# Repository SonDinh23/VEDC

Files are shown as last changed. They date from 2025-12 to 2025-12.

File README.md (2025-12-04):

# VEDC.dev

<div align="center">

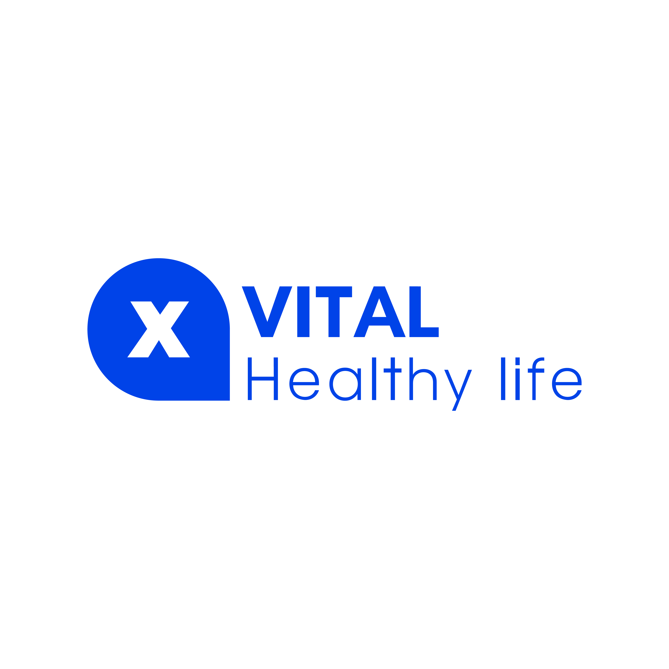
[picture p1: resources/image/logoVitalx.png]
System diagram





<p float="left">
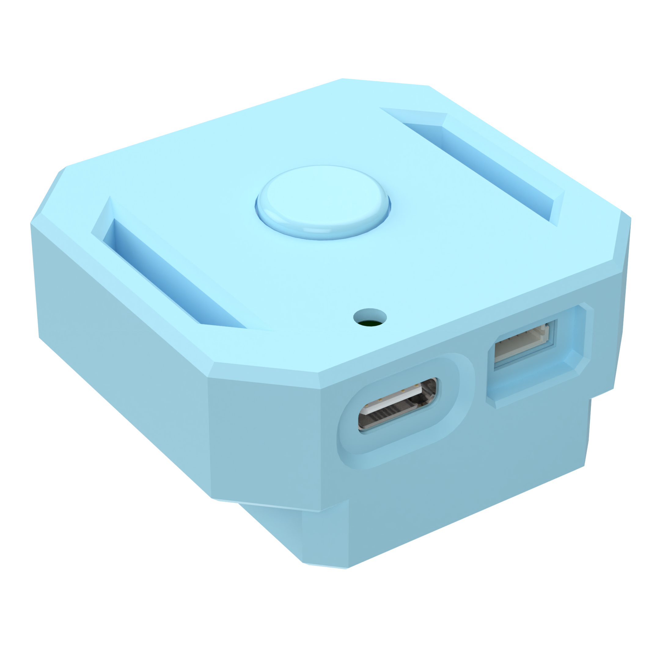
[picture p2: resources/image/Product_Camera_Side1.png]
Product_Camera_Side1

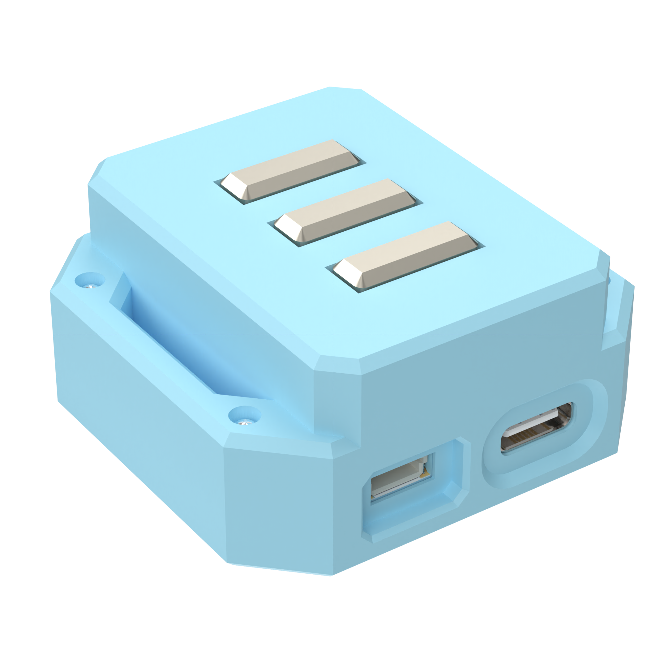
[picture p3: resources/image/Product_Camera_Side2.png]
Product_Camera_Side2

</p>
<sub>
  Vedc v0.1 Front Top product (left), Front Bottom product (right)
</sub>

<p float="left">
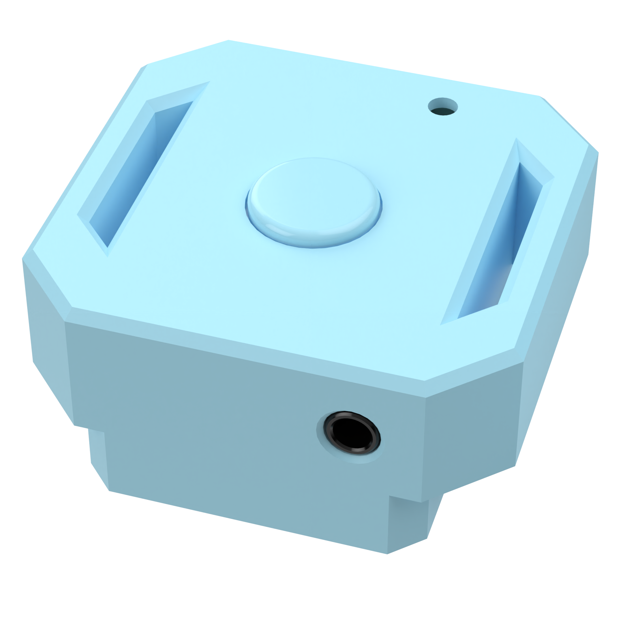
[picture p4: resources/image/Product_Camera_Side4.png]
Product_Camera_Side4

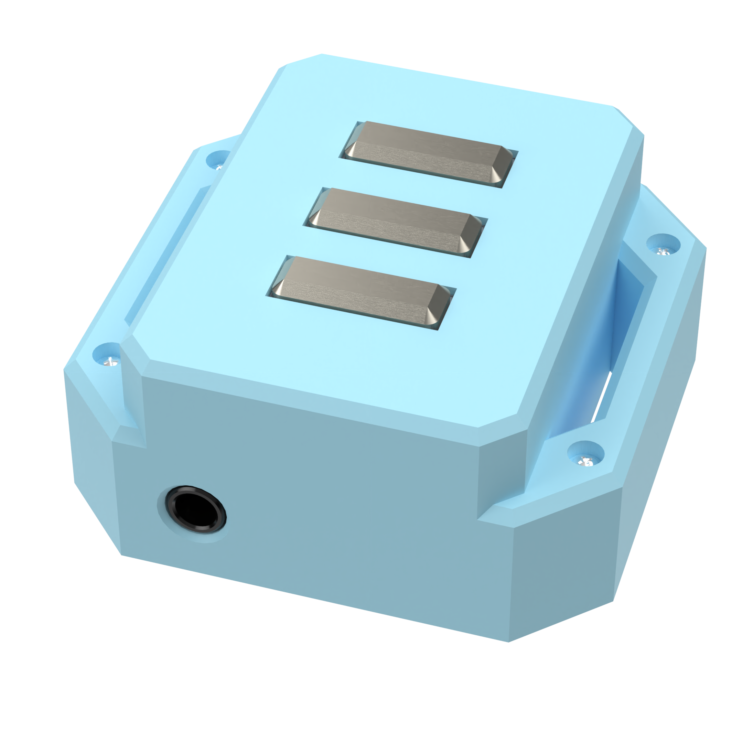
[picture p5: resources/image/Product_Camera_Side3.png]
Product_Camera_Side3

</p>
<sub>
  Vedc v0.1 Back Top product (left), Back Bottom product (right)
</sub>
</div>

## Table of contents

- [About](#about)
- [Platform snapshot](#platform-snapshot)
- [Features](#features)
  - [Hardware](#hardware)
  - [Firmware](#firmware)
  - [Software](#software)
- [Environment & build](#environment--build)
- [Writing apps for the Application Manager](#writing-apps-for-the-application-manager)
- [Licence GPL-3.0](#licence-gpl-30)
- [Thanks](#thanks)

## About

VEDC is a wearable biomedical reference design that blends EMG, ECG, and PPG sensing in a developer-friendly package. The hardware stack is fully captured in KiCad, the firmware targets ESP32-PICO-V3-02 via PlatformIO, and all production assets live in this repo so you can reproduce the build or remix it for your own research.

## Platform snapshot

| Item | Detail |
| --- | --- |
| MCU | ESP32-PICO-V3-02 (dual-core Xtensa®, Wi-Fi + BLE, 8 MB flash, 2 MB PSRAM) |
| Sensors | EMG analog front-end, ECG (AD8232), PPG module, 6-axis IMU, magnetometer |
| Connectivity | Wi-Fi 2.4 GHz, Bluetooth v4.2, USB-C (CP2102N), TWAI®/CAN-ready |
| Power | Single-cell Li-Ion + TP4056 charger + XC6220 LDO + smart power-path on MainPCB |
| Target use | Physiology research, medical wearables prototyping, advanced hobby builds |

### Core silicon & companion parts

- ESP32-PICO-V3-02 ([datasheet](https://documentation.espressif.com/esp32-pico_series_datasheet_en.pdf)) with Xtensa® LX6 up to 240 MHz, Wi-Fi/BLE, Ethernet MAC and TWAI®.
- Torex [XC6220B331MR-G](https://www.farnell.com/datasheets/2012852.pdf) 1 A, 3.3 V low-noise LDO for the digital rail.
- Silicon Labs [CP2102N-A02-GQFN28](https://www.silabs.com/documents/public/data-sheets/cp2102n-datasheet.pdf) USB-to-UART bridge for flashing, logging and live telemetry.
- Worldsemi [WS2812B-2020](https://www.mouser.com/pdfDocs/WS2812B-2020_V10_EN_181106150240761.pdf) RGB indicator, Murata [PKMCS0909E4000-R1](https://pim.murata.com/en-us/pim/details/?partNum=PKMCS0909E4000-R1) piezo buzzer, Microchip [MCP3204](https://ww1.microchip.com/downloads/en/devicedoc/21298e.pdf) SPI ADC.
- ST [LSM6DSL](https://www.st.com/resource/en/datasheet/lsm6dsl.pdf) IMU + [LIS3MDL](https://www.st.com/resource/en/datasheet/lis3mdl.pdf) magnetometer for motion/orientation tracking.
- Analog Devices [AD8232](https://www.analog.com/media/en/technical-documentation/data-sheets/ad8232.pdf) ECG AFE and a custom EMG front-end for bio-signal capture.
- TPASIC [TP4056](https://datasheet.lcsc.com/lcsc/1809261820_TOPPOWER-Nanjing-Extension-Microelectronics-TP4056-42-ESOP8_C16581.pdf) charger IC for USB-powered Li-Ion management.

## Features

### Hardware

- Three KiCad projects: EMGSensor, MainPCB, and PPG_V1.0. Each board section includes schematics, PCB layout, manufacturing outputs, notes, and galleries.
- Design focus on low-noise analog front-ends, modular interconnects, and easy probing during validation.
- Production-ready assets: BOM, pick-and-place, netlist, and positional data are stored under every `production/` folder.

[Browse board documentation →](hardware/README.md)

### Firmware

- ESP-IDF/PlatformIO stack targeting ESP32-PICO-V3-02 with FreeRTOS scheduling, NimBLE-based BLE services, USB-UART telemetry, and low-power modes.
- Sensor pipelines for EMG/ECG/PPG including digital filtering, adaptive baseline tracking, and event triggers for motion artifacts.
- Modular drivers housed under `firmware/Embedded/lib/` plus an application layer that streams metrics to BLE characteristics or logs via UART.
- Includes board bring-up helpers (rail monitors, sensor self-tests) and a configurable command shell.

[Read the full firmware guide →](firmware/README.md)

### Software

- Companion tooling (desktop/mobile) is planned to visualize BLE data streams, annotate sessions, and push OTA payloads.
- Current repo includes assets and API constraints so third parties can prototype dashboards or research tools ahead of the official release.
- Planned features: live waveform view, biomarker extraction scripts, and CSV export for MATLAB/Python workflows.

Have tooling to share? Open an issue so we can link it here.

## Environment & build

### Requirements

- VS Code with the PlatformIO IDE extension (or PlatformIO Core CLI).
- Python 3.10+ (PlatformIO manages the toolchain, but Python is still required).
- KiCad 7+ if you plan to edit the hardware.
- Git LFS for large media assets (images/live captures).

### Quick start

1. Clone the repo: `git clone https://github.com/SonDinh23/VEDC.git && cd VEDC`.
2. Open VS Code -> `firmware/` folder -> PlatformIO will auto-configure the environment.
3. Build: `pio run` (or the PlatformIO Build button).
4. Flash: connect the board over USB-C, then `pio run -t upload`.
5. Monitor logs: `pio device monitor` for UART output, or use the BLE explorer of your choice to view live characteristics.
6. Hardware tweaks: jump into `hardware/README.md` to pick the board you want to fabricate or review.

## Writing apps for the Application Manager

- The Application Manager exposes hooks for real-time sensing apps (recording, feedback) and offline routines (log replay, calibration).
- Apps are plain C++ modules that register tasks, BLE endpoints, and menu entries; use the existing patterns under `firmware/Embedded/src/` and supporting libraries in `firmware/Embedded/lib/` as templates.
- Keep apps lightweight: offload heavy analytics to the companion software via BLE or UART streaming.
- Submit a PR or discussion thread before merging new app types so we can document protocol additions for users.

## Licence GPL-3.0

This project is licensed under the GNU GPLv3.  
Compared to permissive licences like MIT, GPLv3 requires that if you modify this code and distribute your version (including in commercial products), you must also release your changes under the same GPLv3 licence and provide the corresponding source code.  

This way, everyone can benefit from improvements built on top of this project.  
If this licence causes issues for your intended use, feel free to contact me – I’m open to discussing alternatives.

## Thanks

Huge thanks to the open-source communities behind ESP-IDF, PlatformIO, KiCad, and the component vendors whose public documentation made reverse-engineering painless. Additional appreciation goes to early testers who provided waveform captures and enclosure feedback. Reach out if you want to be listed here or contribute design critiques.

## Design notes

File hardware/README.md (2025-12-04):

# 🔧 Hardware Reference

Reference hub for every PCB in the VEDC stack. Each section collects the essential narrative (what the board does), quick specs, manufacturing artifacts, bring-up notes and a gallery that matches the files committed to this repo.

## 📌 At-a-glance

| Board | Functional role | Primary interfaces | Manufacturing kit |
| --- | --- | --- | --- |
| [EMGSensor](#emgsensor) | Surface EMG analog front-end with selectable filtering | Differential electrodes, analog output to MainPCB/ADC | `EMGSensor/*.kicad_*`, `EMGSensor/production/` |
| [MainPCB](#mainpcb) | System backplane: power, MCU, sensor connectors & user IO | USB-C, SPI, I2C, GPIO, battery charger, programming header | `MainPCB/*.kicad_*`, `MainPCB/production/` |
| [PPG_V1.0](#ppg_v10) | Optical heart-rate/SpO2 module (LED driver + TIA) | LED drive, photodiode TIA, analog output to MainPCB | `PPG_V1.0/*.kicad_*`, `PPG_V1.0/production/` |

---

## 🧠 EMGSensor

### Highlights
- Low-noise EMG front-end with band-pass filtering and input protection.
- Differential electrode inputs converted to a conditioned analog output for the main MCU/ADC.
- Designed to keep the analog ground plane quiet and isolated from digital switching noise.

### Quick specs

| Parameter | Detail |
| --- | --- |
| Signal type | Differential surface EMG |
| Input range | Microvolt → millivolt (depends on electrode placement) |
| Bandwidth | Application-configurable band-pass |
| Output | Analog to `MainPCB` or external ADC |

### Manufacturing files
- `EMGSensor/EMGSensor.kicad_sch`
- `EMGSensor/EMGSensor.kicad_pcb`
- `EMGSensor/production/` (BOM, placements, netlist, positions)

### Build & test checklist
- Keep electrode traces short/shielded and preserve the analog ground island.
- Verify input protection and supply rails before connecting electrodes to humans.
- Adjust filter corners so they align with sampling rate and targeted muscle group.

### Gallery

<table>
  <tr>
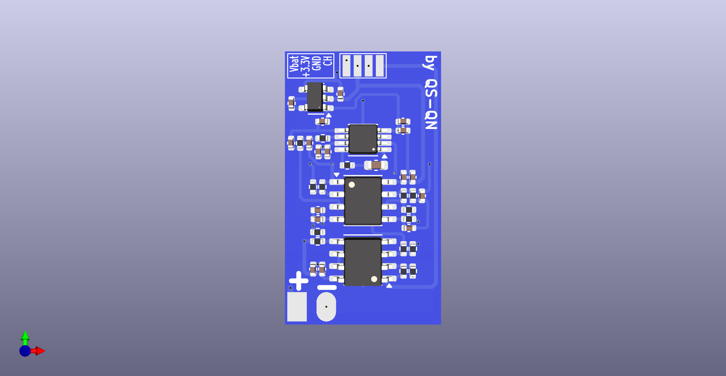
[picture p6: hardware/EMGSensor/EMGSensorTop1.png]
EMGSensor Top 1
    <td align="center"><br><small>Top — module overview</small></td>
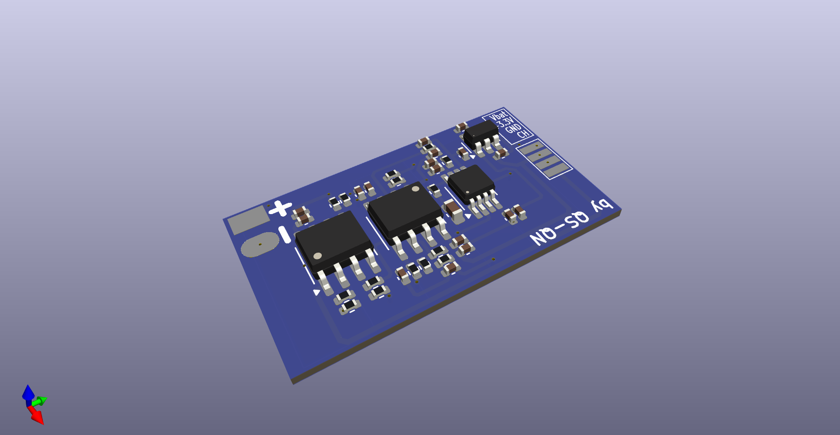
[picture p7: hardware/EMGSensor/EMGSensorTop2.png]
EMGSensor Top 2
    <td align="center"><br><small>Top — amplifier/filter</small></td>
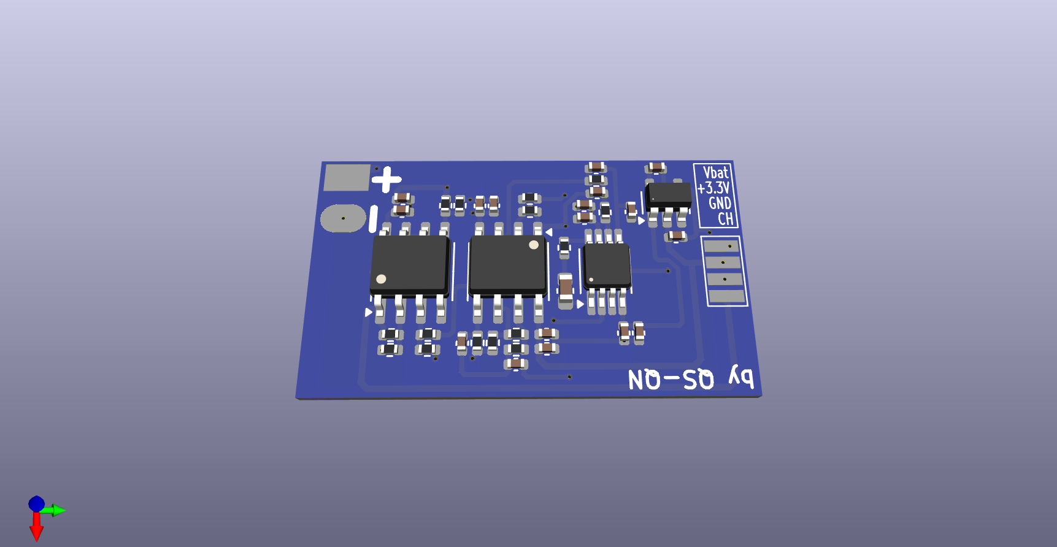
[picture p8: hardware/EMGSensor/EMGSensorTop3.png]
EMGSensor Top 3
    <td align="center"><br><small>Top — connectors</small></td>
  </tr>
  <tr>
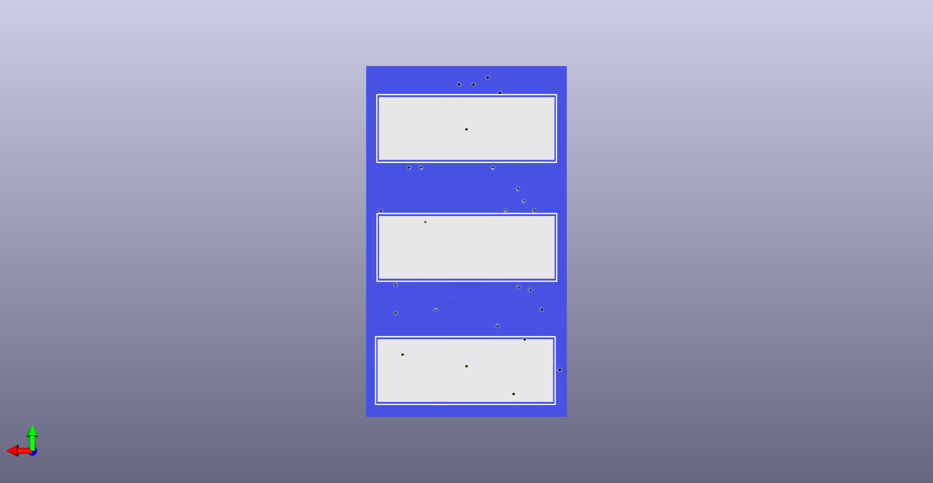
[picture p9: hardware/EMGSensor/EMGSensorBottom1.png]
EMGSensor Bottom 1
    <td align="center"><br><small>Bottom — solder side</small></td>
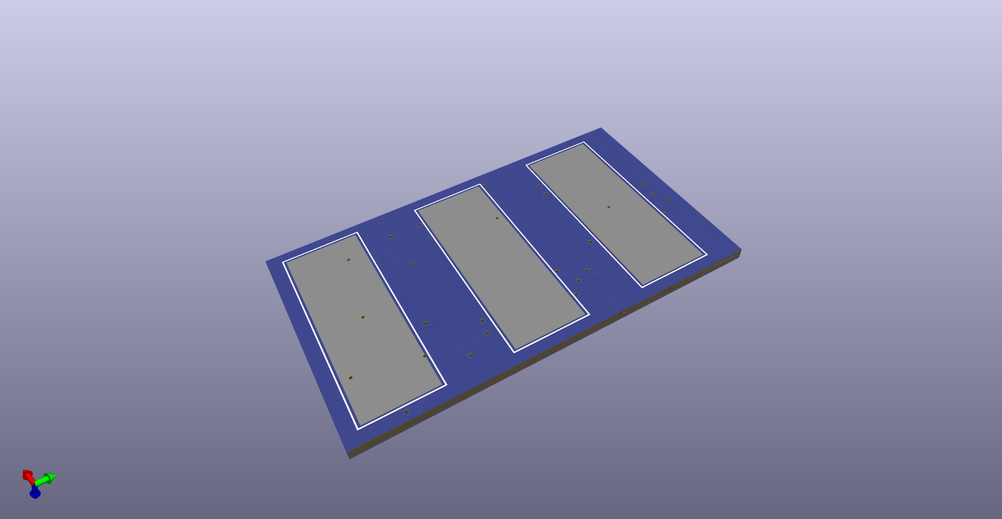
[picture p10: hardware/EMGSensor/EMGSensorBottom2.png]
EMGSensor Bottom 2
    <td align="center"><br><small>Bottom — ground pours</small></td>
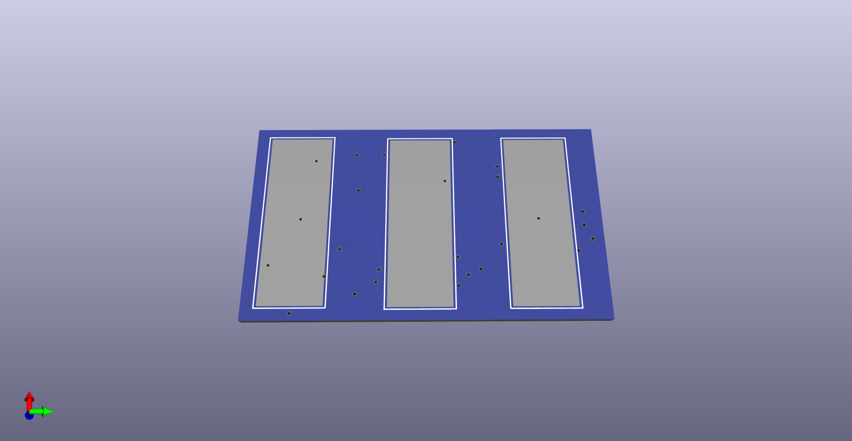
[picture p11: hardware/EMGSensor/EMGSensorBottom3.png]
EMGSensor Bottom 3
    <td align="center"><br><small>Bottom — component placement</small></td>
  </tr>
</table>

---

## 🧭 MainPCB

### Highlights
- Primary compute board with ESP32 module, battery charging/power-path management and sensor interconnects.
- Hosts debug/programming headers, USB-UART bridge, IMU/ADC expansion headers and NeoPixel/buzzer drivers.
- Provides regulated rails (3V3 etc.) and mounting keep-outs for future enclosures.

### Quick specs

| Parameter | Detail |
| --- | --- |
| Core function | Power distribution + embedded processing |
| Key rails | Battery, charger IC, 3V3 LDO, load switches |
| Interfaces | USB/serial, SPI, I2C, ADC, GPIO, programming header |

### Manufacturing files
- `MainPCB/MainPCB.kicad_sch`
- `MainPCB/MainPCB.kicad_pcb`
- `MainPCB/production/` (BOM, placements, netlist, positions)

### Build & test checklist
- Cross-check BOM vs placement before assembly to avoid variant mix-ups.
- Validate mechanical clearances/keep-outs when fitting into an enclosure.
- Probe test points for each rail during bring-up; confirm charger and LDO thermals.

### Gallery

<table>
  <tr>
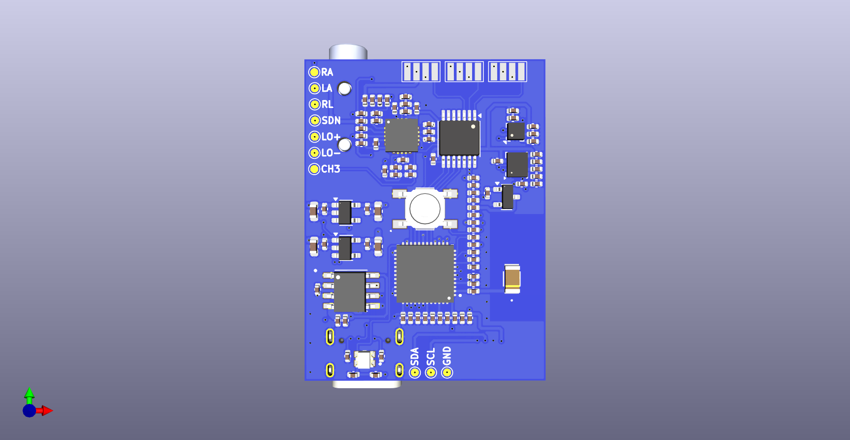
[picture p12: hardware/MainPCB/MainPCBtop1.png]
MainPCB top 1
    <td align="center"><br><small>Top — overview</small></td>
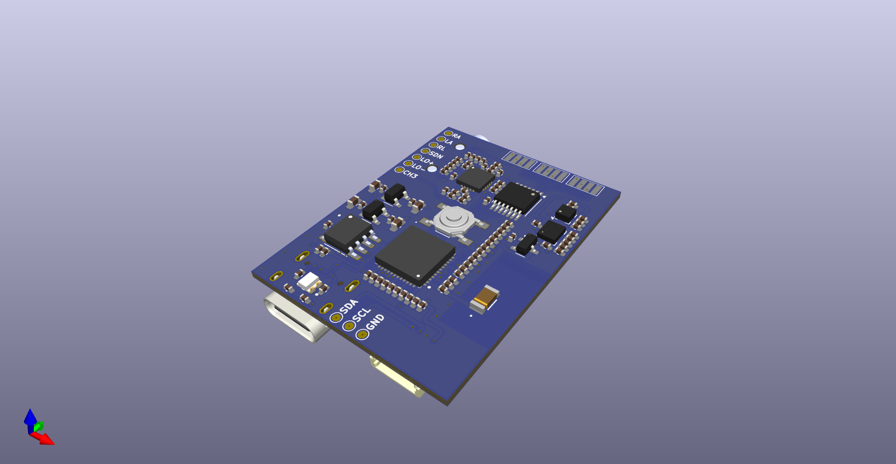
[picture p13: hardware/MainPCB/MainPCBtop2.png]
MainPCB top 2
    <td align="center"><br><small>Top — MCU & IO</small></td>
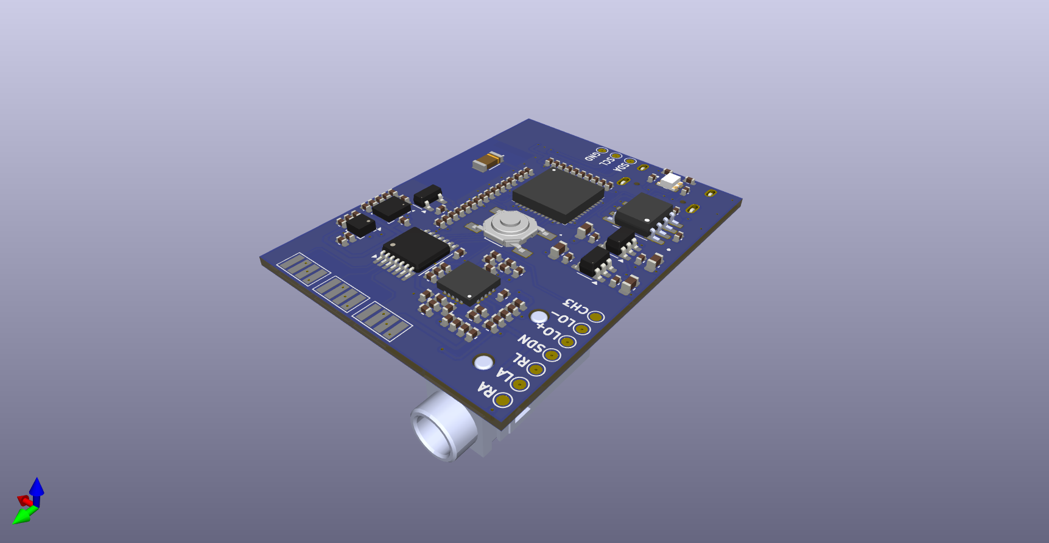
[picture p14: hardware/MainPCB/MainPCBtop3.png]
MainPCB top 3
    <td align="center"><br><small>Top — power subsystem</small></td>
  </tr>
  <tr>
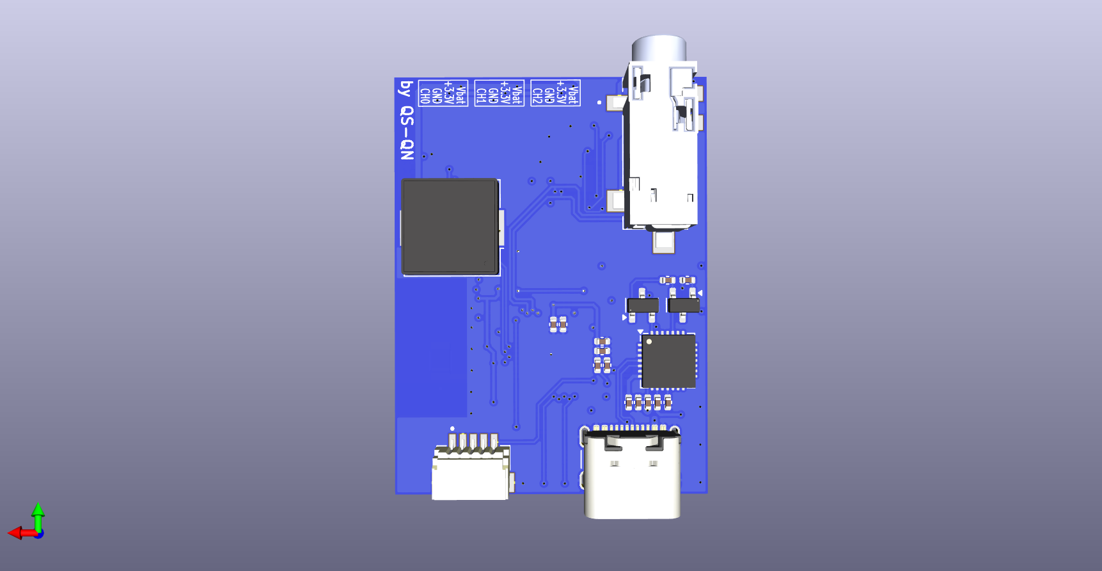
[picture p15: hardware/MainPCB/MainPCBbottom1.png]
MainPCB bottom 1
    <td align="center"><br><small>Bottom — solder side</small></td>
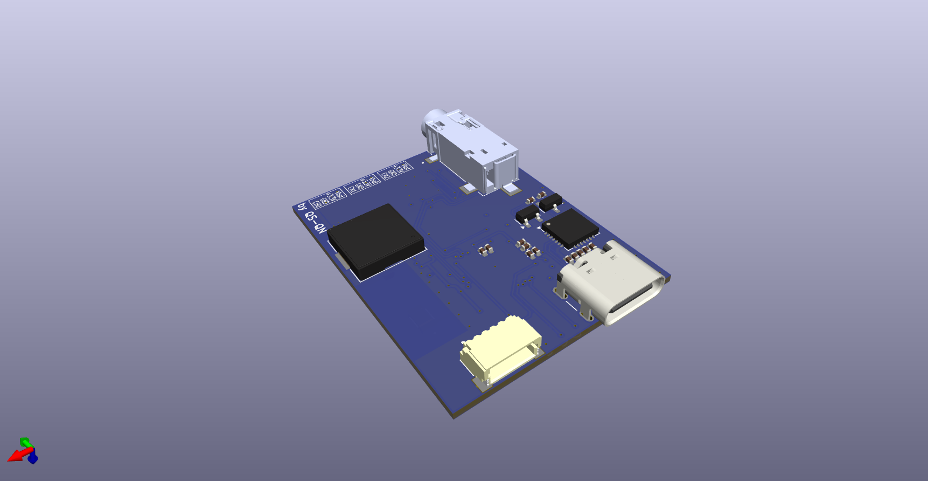
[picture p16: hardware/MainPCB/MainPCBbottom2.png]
MainPCB bottom 2
    <td align="center"><br><small>Bottom — pours & routing</small></td>
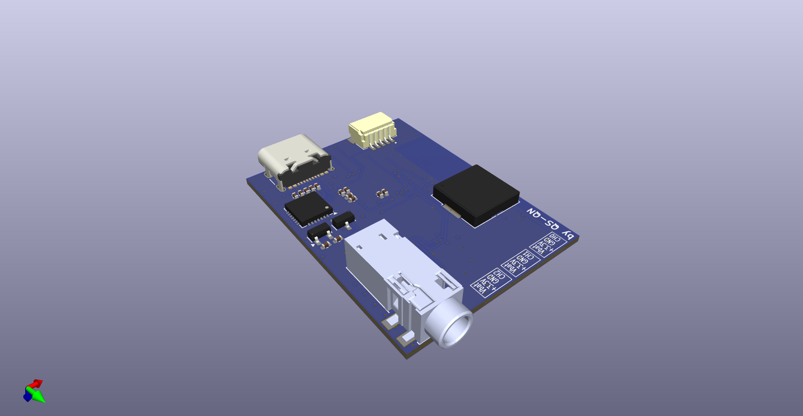
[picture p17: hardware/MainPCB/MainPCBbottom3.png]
MainPCB bottom 3
    <td align="center"><br><small>Bottom — placement</small></td>
  </tr>
</table>

---

## 💡 PPG_V1.0

### Highlights
- Dual-LED photoplethysmography front-end with transimpedance amplifier.
- Layout keeps LED/photodiode path compact to reduce crosstalk and improve tissue coupling.
- Analog output routes directly to MainPCB analog inputs or an external ADC.

### Quick specs

| Parameter | Detail |
| --- | --- |
| Role | Optical heart-rate / blood-volume sensing |
| Key blocks | LED driver, photodetector + TIA, post-filtering |
| Output | Analog to `MainPCB` / ADC |

### Manufacturing files
- `PPG_V1.0/PPG_V1.0.kicad_sch`
- `PPG_V1.0/PPG_V1.0.kicad_pcb`
- `PPG_V1.0/production/` (BOM, placements, netlist, positions)

### Build & test checklist
- Align LEDs and photodiode carefully; even small misalignments affect signal quality.
- Tune LED current and TIA feedback for the target SNR vs power budget.
- Shield the sensor head from ambient light during characterization.

### Gallery

<table>
  <tr>
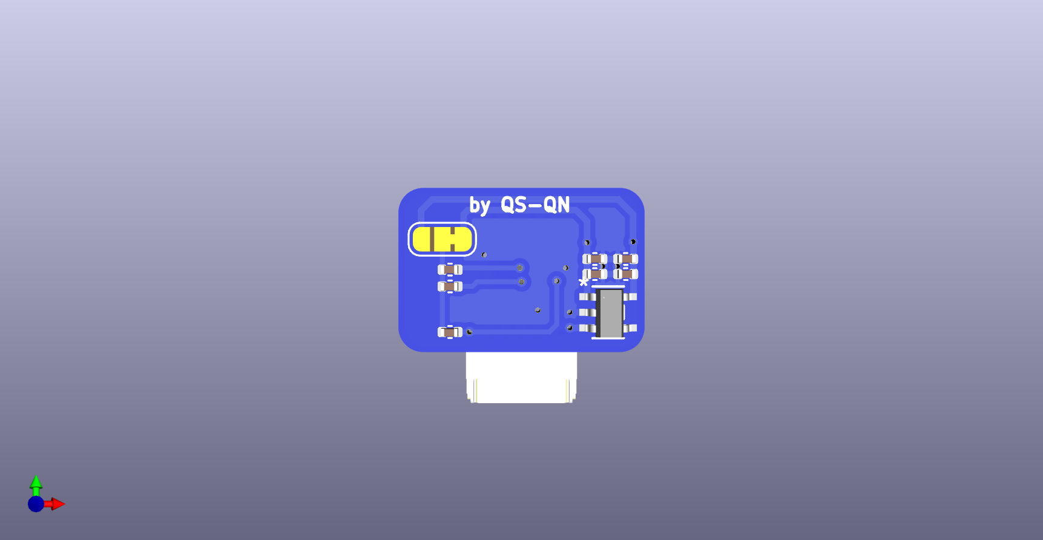
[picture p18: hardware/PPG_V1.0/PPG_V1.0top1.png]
PPG top 1
    <td align="center"><br><small>Top — overview</small></td>
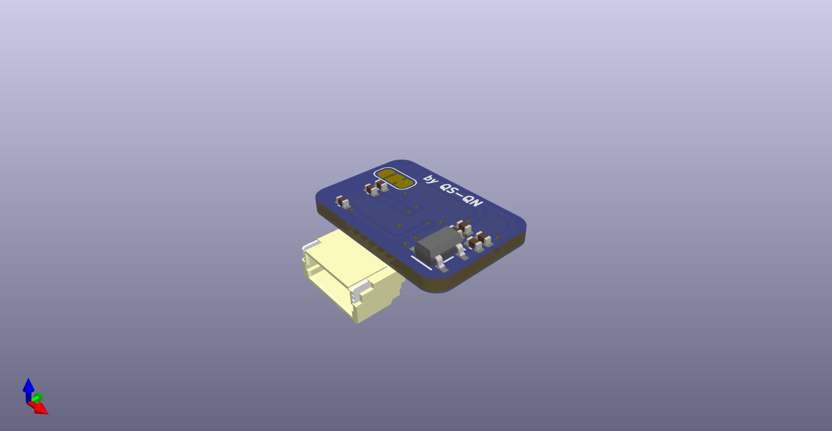
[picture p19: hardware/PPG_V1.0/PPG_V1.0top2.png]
PPG top 2
    <td align="center"><br><small>Top — LED/receiver zone</small></td>
  </tr>
  <tr>
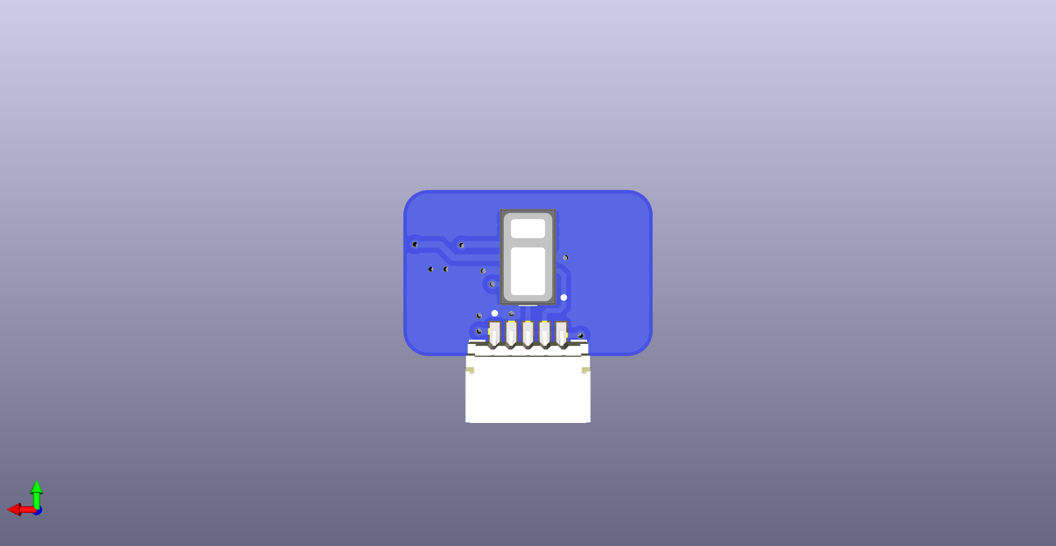
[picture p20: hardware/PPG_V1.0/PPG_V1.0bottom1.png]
PPG bottom 1
    <td align="center"><br><small>Bottom — solder side</small></td>
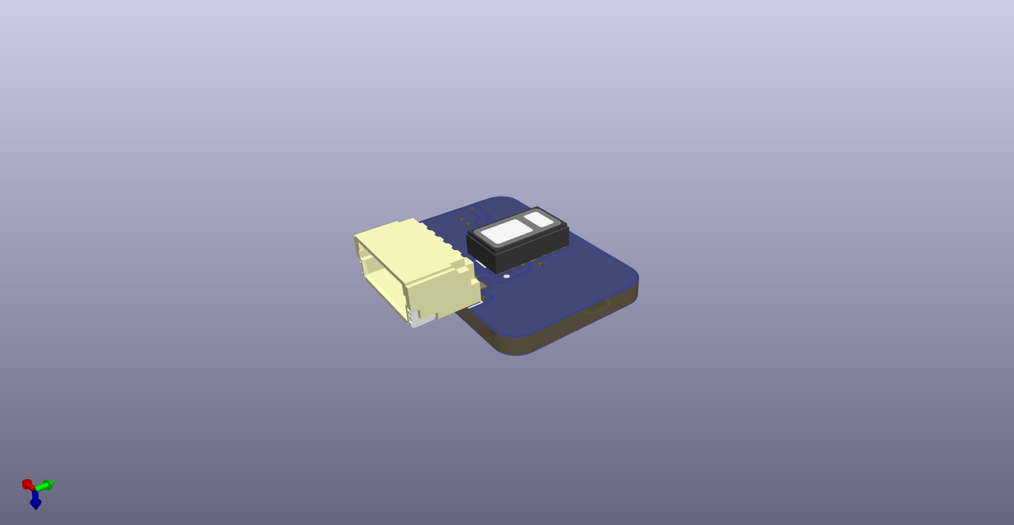
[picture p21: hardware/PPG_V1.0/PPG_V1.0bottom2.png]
PPG bottom 2
    <td align="center"><br><small>Bottom — placement view</small></td>
  </tr>
</table>

---

## 🖼️ Image & path guidance

- Use forward slashes `/` in Markdown image paths; all current links are relative to this README.
- Example snippet: `![EMG front](EMGSensor/EMGSensorTop1.png)`.
- GitHub renders images only after the corresponding PNG/SVG files are committed and pushed.
- Need a different layout (per-board README, thumbnail sizes, PDF gallery)? Let me know and I can spin up that structure quickly.

---

_Last refreshed: see git history for author/date of the latest board update._

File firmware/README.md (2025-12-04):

# ⚙️ Firmware

Firmware for VEDC runs on an ESP32-PICO-V3-02 and is organised as a PlatformIO project under `firmware/Embedded`. The codebase orchestrates EMG/IMU, ECG and PPG sensing, manages power and charging, drives haptic/audio feedback, and exposes a BLE interface (NimBLE) for data streaming, control and OTA firmware updates.

## 📁 Directory layout

| Path | Description |
| --- | --- |
| `Embedded/platformio.ini` | PlatformIO environment (`env:mainVEDC`) configuring ESP32 board, PSRAM/flash, COM ports, build flags and third-party libraries. |
| `Embedded/src/MainVEDC.cpp` | Main application entry: hardware bring-up, FreeRTOS task creation, BLE orchestration, power management loop. |
| `Embedded/lib/Son_WearableSensor` | Sensor pipeline (EMG, ECG, PPG, IMU fusion), data encoding and buffer publication. |
| `Embedded/lib/Son_BLEPeripheral` | BLE stack (Information + Controller services), OTA handler, advertising helpers. |
| `Embedded/lib/Son_BLEServiceManager` | Helper template for registering NimBLE characteristics/read-write/notify callbacks. |
| `Embedded/lib/Son_BuzzerMusic` | LEDC-based buzzer driver with predefined alert tones. |
| `Embedded/lib/Son_LSM6DSL` | Driver and helpers for the ST LSM6DSL IMU (I²C/SPI). |
| `Embedded/lib/Son_Filter` | Utility macros (low-pass filters, half-float conversion, mapping helpers). |
| `Embedded/include/` | Place for project-wide headers (PlatformIO convention). |
| `.pio/`, `.vscode/`, `test/` | Build artifacts, VS Code configuration, and PlatformIO test scaffolding. |

## 🧩 System architecture

- **Hardware targets**: ESP32-PICO-V3-02 (`esp32dev` profile) with 8 MB flash, PSRAM enabled (`-DBOARD_HAS_PSRAM`, `-mfix-esp32-psram-cache-issue`). External peripherals include MCP3204 ADC (EMG/ECG), MAX30105 PPG sensor, LSM6DSL IMU, LIS3MDL magnetometer, LED driver, buzzer, and WS2812 NeoPixel indicator.
- **RTOS tasks** (created from `setup()`): dedicated FreeRTOS tasks for EMG/IMU, ECG, PPG, “all sensors”, BLE sync, and a Manager task. Tasks are coordinated via `isRunningTaskSystem[]` flags and suspended/resumed depending on the active sensing mode.
- **Modes**: `MODE_WEARABLE_EMG_IMU`, `MODE_WEARABLE_ECG`, `MODE_WEARABLE_PPG`, `MODE_WEARABLE_ALL`, selected through BLE Controller characteristic. Modes are persisted via `Preferences` so devices restart in last-used mode.
- **Feedback + power**: NeoPixel colour indicates current mode or status, buzzer plays cues (connect, warning, OTA, low battery). Power management monitors charger pins, battery sense, handles deep sleep, wake-up by button/GPIO, and triggers low-battery alarms.
- **Communication**: NimBLE-based GATT server exposes two services: Information (version/name/hardware + OTA) and Controller (mode selection + sensor/battery notifications). BLE MTU set to 517 bytes for efficient streaming.

## 🔄 Runtime flow

1. **Boot & init**: `setup()` configures GPIO, SPI, ADC, NeoPixel, buzzer and sensors, then starts BLE and waits for optional button-triggered wake. PSRAM and SPIFFS are initialised to cache calibration data.
2. **BLE connection window**: `BLEPeripheral::waitConnect()` advertises for up to 60 s while pulsing LEDs/buzzer. If no connection occurs, the device can enter sleep depending on button state.
3. **Sensor tasks**: Once running, tasks continuously sample their respective sensors. Manager task monitors BLE mode selection and resumes/suspends tasks, updates LED colour, and keeps a running battery estimate.
4. **Data path**: Sensor classes push processed samples into `bufferNotify*` arrays. `BLEPeripheral::notifyData()` calls the appropriate Controller notify function, which sends packets as half-floats/uint32 via GATT characteristics.
5. **Power supervision**: `onPower()` polls button, BLE state and charger lines. It enforces timeouts, restarts advertising if disconnected, alarms on low battery (<15 %) and forces sleep below 5 %.
6. **Sleep/OTA**: Button long-press toggles deep sleep via `onSleep()`/`deepSleep()`. OTA is handled entirely over BLE (see below).

## 🧪 Sensor pipelines & algorithms

### ⚡ EMG + IMU
- Sampling: MCP3204 channel read at ~1 kHz (`CYCLE = 1000 µs`).
- Filtering: High-pass (KickFiltersRT) followed by configurable Kalman filter; EMG stored as half-float. IMU orientation uses a quaternion-based fusion (Madgwick-style) combining LSM6DSL gyro/accel with LIS3MDL magnetometer (tilt-compensated heading + complementary filter on yaw).
- Output payload: EMG magnitude + roll, pitch, yaw + elapsed cycle time.

### ❤️ ECG
- Hardware: MCP3204 differential inputs with lead-off detection pins (`PIN_LO_POSITIVE_ECG`, `PIN_LO_NEGATIVE_ECG`).
- Processing chain: high-pass filter (1st order), derivative, squaring, moving window integral (Pan–Tompkins inspired). Adaptive thresholds track signal/noise peaks; RR intervals filtered via EMA to compute heart rate.
- Output payload: lead status bits, filtered analog sample, heart rate half-float.

### 💡 PPG (MAX30105)
- Acquisition: Red/IR LEDs, 100 sps sample rate, decimated by factor 4 for bandwidth reduction. Buffer length 100 samples (~4 s) with recomputation stride 25 samples.
- Algorithms: Maxim `maxim_heart_rate_and_oxygen_saturation()` for HR / SpO₂; EMA smoothing for HR; logistic regression (`logistic_model`) fuses HR + SpO₂ to estimate SmO₂.
- Output payload: raw Red/IR (32-bit), filtered HR/SpO₂/SmO₂ half-floats.

### 🔋 Battery & charging
- `getBattery()` converts ADC millivolts (voltage divider) into percentage with clamping between `BATTERY_MIN` (3.2 V) and `BATTERY_MAX` (4.15 V). Thresholds trigger blink/beep alarms and enforced sleeps; charging detection resets CPU if charger inserted while running (in non-debug builds).

## 📡 BLE stack & OTA

- **Information service** (`WEARABLE_INFORMATION_SERVICE_UUID`)
	- Characteristics: OTA (`OTA_CHAR_UUID`), Device Name, Hardware Name.
	- OTA process: client writes `START_OTA`, streams binary chunks, writes `END_OTA`. ESP32 writes to next OTA partition via `esp_ota_begin/esp_ota_write/esp_ota_end` and reboots when complete.
	- Device name/hardware stored in NVS (`Preferences`) and mirrored to advertisement data.

- **Controller service** (`WEARABLE_CONTROLLER_SERVICE_UUID`)
	- Characteristics: Mode select, EMG/IMU notify, ECG notify, PPG notify, All-sensor (reserved), Battery notify.
	- Notifications use MTU 517 for efficient 20+ byte packets. Mode writes accept ASCII digits representing `mode_wearable_sensor_t` enum.

## 🛠️ Building & flashing

Requirements: PlatformIO CLI or VS Code extension, ESP32 toolchain, USB connection recognised as `COM3` (adjust as needed).

	# 1. Install deps (once)
	pip install platformio

	# 2. Build
	cd firmware/Embedded
	pio run -e mainVEDC

	# 3. Flash firmware (ensure board on COM3)
	pio run -e mainVEDC -t upload

	# 4. Open serial monitor at 115200 baud
	pio device monitor -p COM3 -b 115200

Key build settings (`platformio.ini`):
- `platform = espressif32 @ 6.11.0`, `framework = arduino`, `board = esp32dev`.
- PSRAM/flash config via `board_build.*` options (8 MB QIO, custom partitions `default_8MB.csv`).
- External libraries: MCP320x, SparkFun MAX3010x, SimpleKalmanFilter, KickMath/KickFiltersRT, ESP32Time, NimBLE-Arduino, ArduinoJson, Adafruit NeoPixel + LIS3MDL.

## ⚠️ Operational notes & cautions

- **Task watchdog**: `esp_task_wdt` is fed in sensor loops and OTA handler—avoid adding blocking code without feeding WDT.
- **PSRAM**: Build flags enable PSRAM cache workaround; ensure board definition matches hardware (otherwise random crashes may occur).
- **Sensor grounding**: EMG/ECG inputs are high-impedance and sensitive—maintain shielding and protect against ESD when connecting electrodes.
- **Battery thresholds**: `BATTERY_MIN/BATTERY_MAX` are calibrated for single-cell Li-ion. Adjust if using different chemistry.
- **BLE OTA**: Client must honour START/END messages and send chunks quickly; abort resets OTA session. Ensure adequate battery before OTA.
- **Button handling**: Long press toggles sleep; double-check `PIN_BUTTON` wiring before changing logic to avoid stuck-sleep states.

## 🚀 Extending the firmware

- Add new sensors by extending `WearableSensor` (new mode, buffer, encoder) and exposing a characteristic via `BLEController`.
- To adjust sampling or filtering, modify constants (`FS`, `CYCLE`, Kalman gains, logistic coefficients) inside `Son_WearableSensor` and reflash.
- For additional UI cues, update `BuzzerMusic` or NeoPixel colours inside `ManagerOP` when entering modes.

For questions or contributions, open an issue or pull request in this repository. When contributing code, run `pio run -e mainVEDC` before submitting to ensure the firmware compiles.

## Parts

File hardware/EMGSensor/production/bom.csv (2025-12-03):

Designator | Footprint | Quantity | Value | LCSC Part #
_2, |  | 2
C1, C14, C24, C3, C9 | 0402 | 5 | 4.7uF
C10, C13, C15, C2, C23, C25, C26, C27, C28 | 0402 | 9 | 100nF
C11 | 0603 | 1 | 10uF
C12, C22, C5 | 0402 | 3 | 1uF
R1 | 0402 | 1 | 220R
R14 | 0402 | 1 | 2.8K
R15, R19, R21, R6 | 0402 | 4 | 1K
R16, R20, R5 | 0402 | 3 | 3.6K
R17 | 0402 | 1 | 22K
R18 | 0402 | 1 | 33K
R2, R3 | 0402 | 2 | 100K
R4, R7 | 0402 | 2 | 2K
U1 | VSSOP-8_3x3mm_P0.65mm | 1 | INA333xxDGK
U10 | Pad 1 | 1 | Pad
U11 | SOT-23-5 | 1 | TPS60402DBV
U12, U2 | SOIC-8_3.9x4.9mm_P1.27mm | 2 | MCP602
U13 | Pad 4 | 1 | Pad 4
U7 | Pad Battery | 1 | Pad_Battery

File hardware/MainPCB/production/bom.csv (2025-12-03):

Designator | Footprint | Quantity | Value | LCSC Part #
AE1 | ANT_16060A1T_WAL | 1 | RFECA3216060A1T
BZ1 | Buzzer_Murata_PKMCS0909E | 1 | Buzzer
C1, C22, C24, C26, C28 | 0402 | 5 | 1uF
C10, C12, C14, C16, C19, C2, C29, C31, C36, C38, C4, C40, C42, C6, C8 | 0402 | 15 | 4.7uF
C11, C13, C15, C17, C18, C3, C30, C32, C33, C34, C37, C39, C41, C43, C5, C7, C9 | 0402 | 17 | 100nF
C20, C46 | 0402 | 2 | 10nF
C21, C23, C25, C27 | 0603 | 4 | 22uF
C44 | 0402 | 1 | 1nF
C45, C48 | 0402 | 2 | 0.33uF
C47 | 0402 | 1 | 1.5nF
C49, C50 | 0402 | 2 | 0.1uF
D2 | LED_WS2812B2020 | 1 | WS2812B2020
J1 | USB_C_Receptacle_GCT_USB4105-xx-A_16P_TopMnt_Horizontal | 1 | USB_C_Receptacle_USB2.0_16P
J2 | CUI_SJ2-3593D-SMT-TR | 1 | SJ2-3593D-SMT-TR
J3 | JST_SM05B-SRSS-TB_LF__SN_ | 1 | SM05B-SRSS-TB_LF__SN_
Q1, Q2 | SOT-23 | 2 | SS8050
Q3 | SOT-23 | 1 | MMBT2222A
R1, R16, R3, R6 | 0402 | 4 | 0R
R10, R11, R12, R13, R14, R15, R2, R22, R23, R24, R45 | 0402 | 11 | 10K
R17 | 0402 | 1 | 3K
R18, R19, R20 | 0402 | 3 | 200K
R21 | 0402 | 1 | 300K
R25, R43 | 0402 | 2 | 0
R26, R44 | 0402 | 2 | DNP
R27, R30, R34, R35, R37 | 0402 | 5 | 1M
R28, R29 | 0402 | 2 | 1K
R31, R32 | 0402 | 2 | 180K
R33 | 0402 | 1 | 360K
R36 | 0402 | 1 | 100K
R38, R39, R41, R42 | 0402 | 4 | 10M
R4, R5 | 0402 | 2 | 5.1K
R40 | 0402 | 1 | 1.4M
R7 | 0402 | 1 | 4.7K
R8 | 0402 | 1 | 24K
R9 | 0402 | 1 | 47K
S1 | SW_TL3342F160QG | 1 | TL3342F160QG
TP1, TP10, TP2, TP3, TP4, TP5, TP6, TP7, TP8, TP9 | TestPoint_Pad_D1.0mm | 10 | TestPoint_Small
U1 | XCVR_ESP32-PICO-V3-02 | 1 | ESP32-PICO-V3-02
U10, U8, U9 | Pad 4 | 3 | Pad 4
U13 | LFCSP_20 | 1 | AD8232
U15, U5 | SOT-23-5 | 2 | XC6220B331MR
U2 | QFN-28-1EP_5x5mm_P0.5mm_EP3.35x3.35mm | 1 | CP2102N-Axx-xQFN28
U3 | LGA-14_3x2.5mm_P0.5mm_LayoutBorder3x4y | 1 | LSM6DSL
U4 | TSSOP-14_4.4x5mm_P0.65mm | 1 | MCP3204
U6 | SOP127P600X175-9N | 1 | TP4056
U7 | LGA-12_2x2mm_P0.5mm | 1 | LIS3MDL

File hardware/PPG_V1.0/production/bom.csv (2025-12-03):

Designator | Footprint | Quantity | Value | LCSC Part #
C20, C3 | 0402 | 2 | 100nF
C4, C5 | 0402 | 2 | 4.7uF
J3 | JST_SM05B-SRSS-TB_LF__SN_ | 1 | SM05B-SRSS-TB_LF__SN_
R1, R2, R3 | 0402 | 3 | 472
U1 | XDCR_MAX30101EFD_ | 1 | MAX30102EFD_T
U3 | SOT-25_TOR | 1 | XC6220B181MR-G

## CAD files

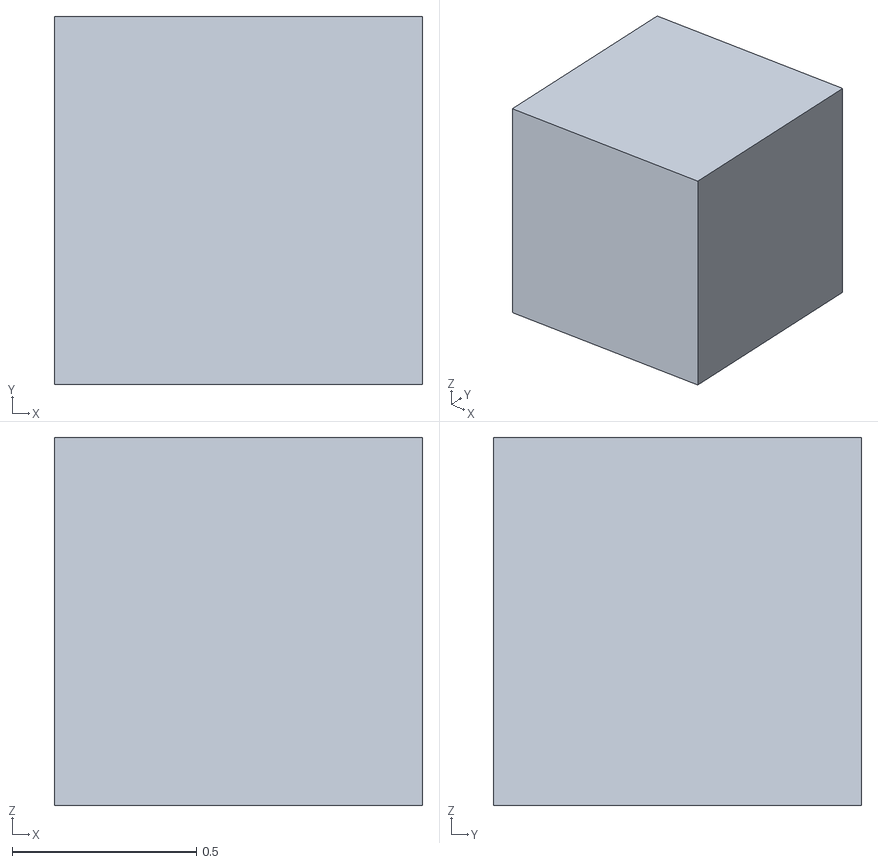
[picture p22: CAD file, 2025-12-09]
app/app_vedc/assets/models/imu.obj
1.00 x 1.00 x 1.00

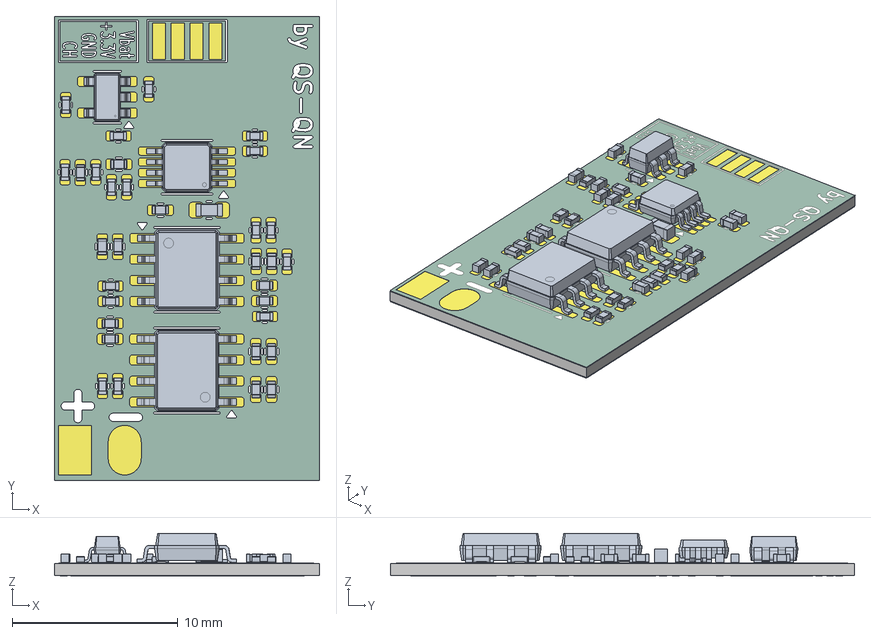
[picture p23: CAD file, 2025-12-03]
hardware/EMGSensor/EMGSensor.step
16.0 x 28.0 x 2.62 mm
C_0402_1005Metric x 17
R_0402_1005Metric x 15
SOT-23-5
SOIC-8_3.9x4.9mm_P1.27mm x 2
VSSOP-8_3x3mm_P0.65mm
C_0603_1608Metric
EMGSensor_copper
EMGSensor_silkscreen
EMGSensor_soldermask
EMGSensor_PCB

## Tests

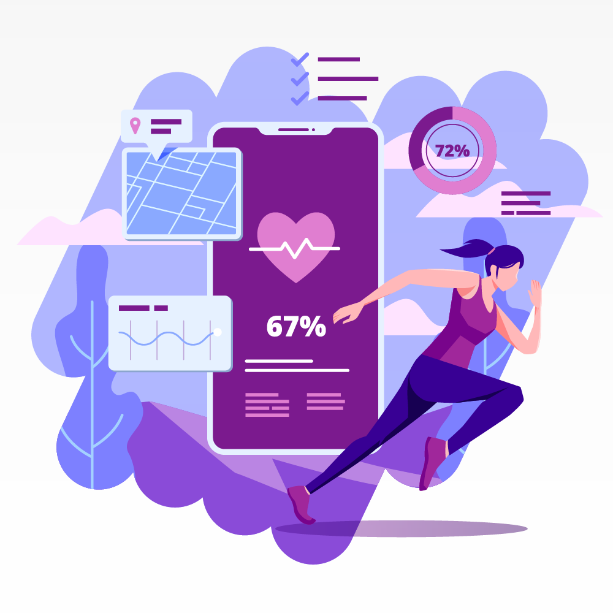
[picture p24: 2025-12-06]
app/app_vedc/assets/images/on_boarding_images/measurement_and_testing.png

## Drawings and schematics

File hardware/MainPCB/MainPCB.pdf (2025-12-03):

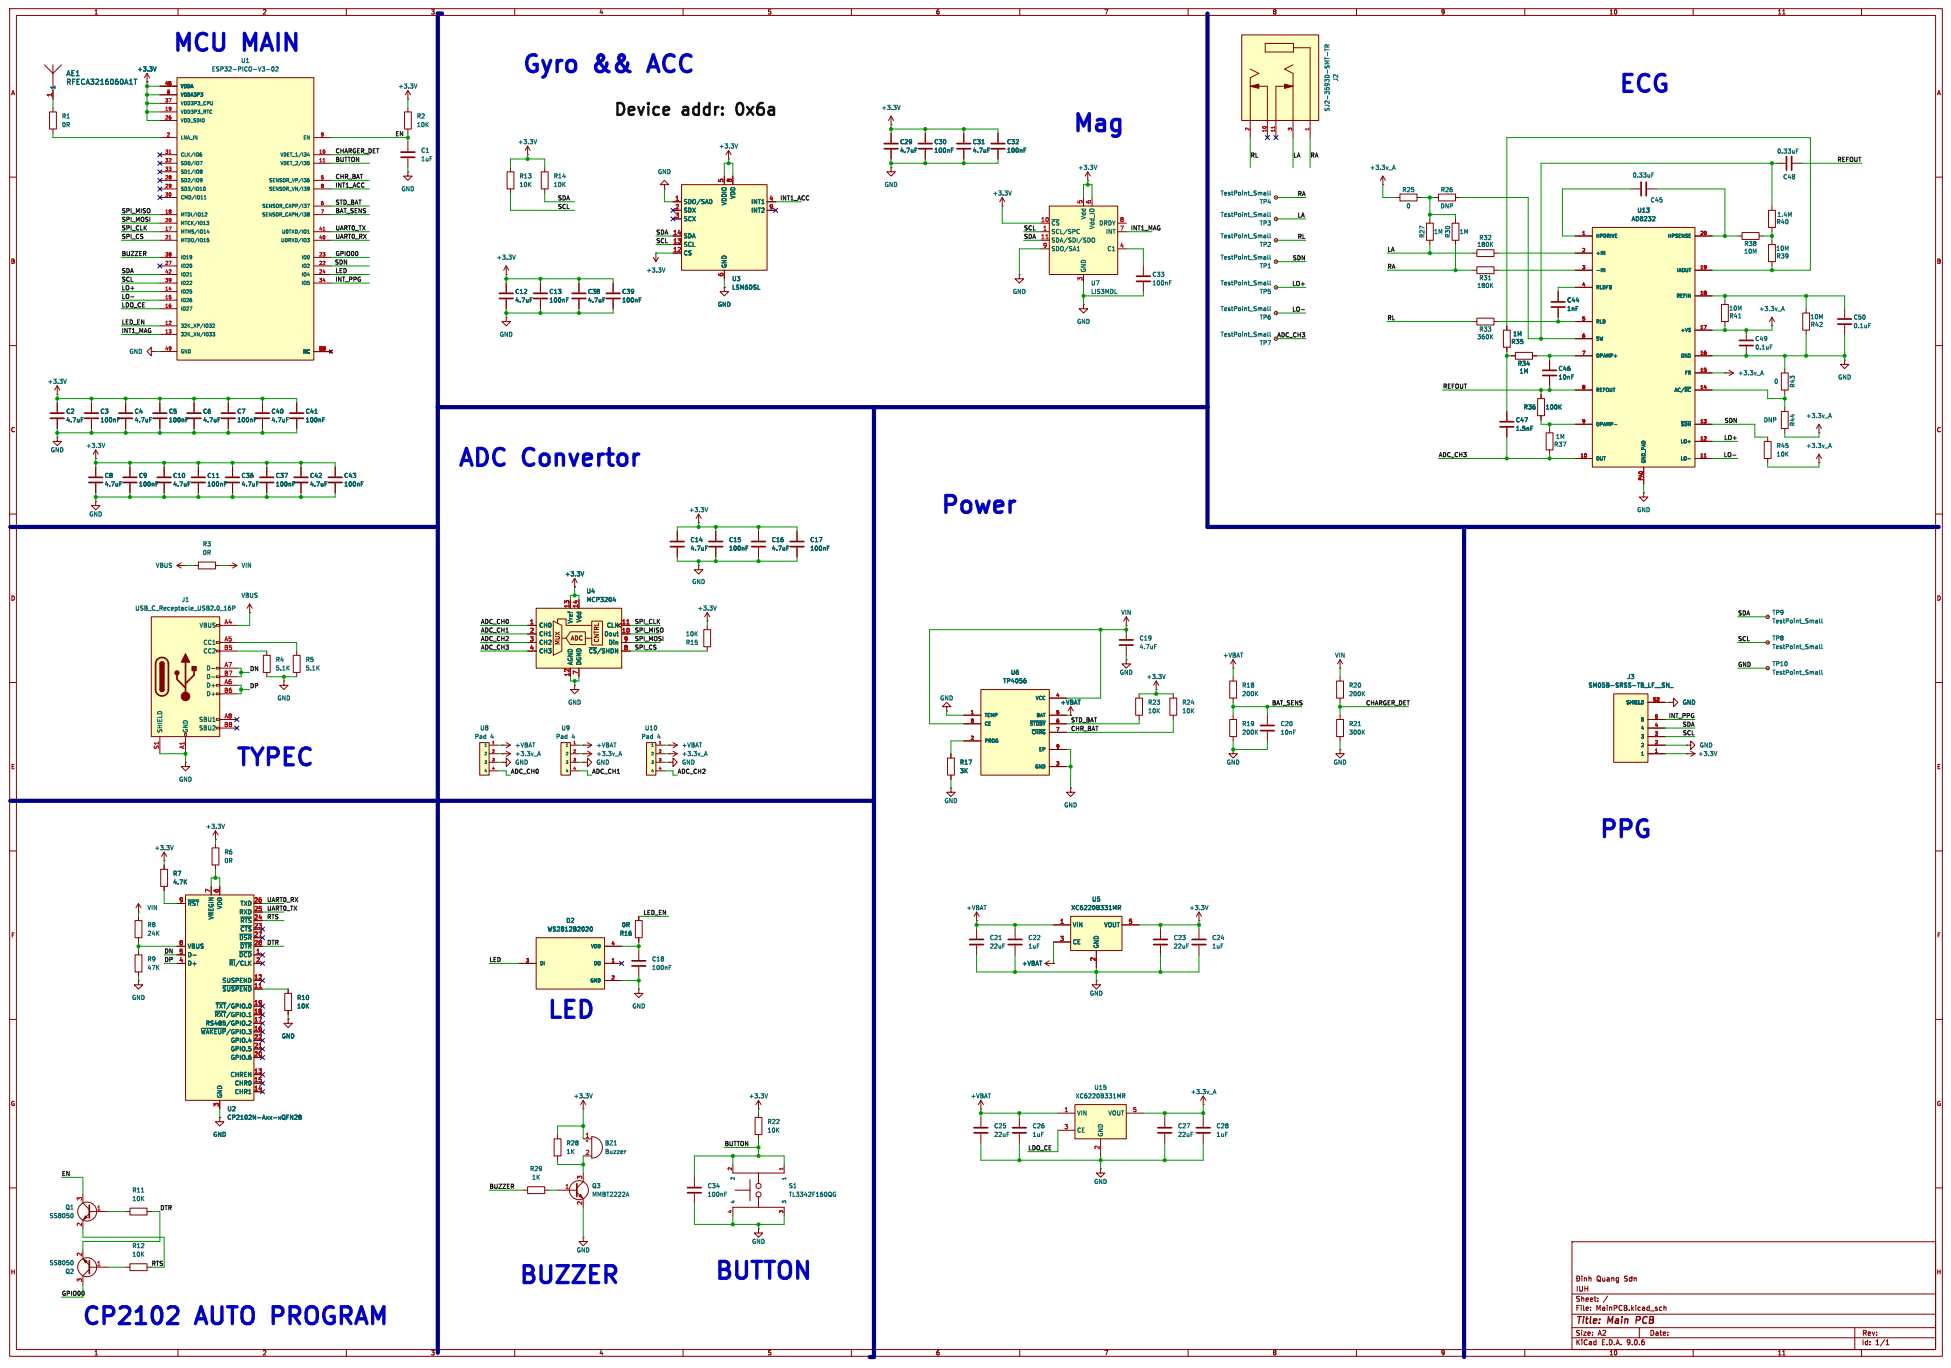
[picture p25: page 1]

7 CLK 11 Dout 10 Din 9 ~{CS}/SHDN 8 U4 MCP3204

7 CLK 11 Dout 10 Din 9 ~{CS}/SHDN 8 R7

3 TXD 26 RXD 25 ~{RTS} 24 ~{CTS} 23 ~{DSR} 27 ~{DTR} 28 ~{DCD}1 ~{RI}/CLK2 SUSPEND 12 ~{SUSPEND}11 ~{TXT}/GPIO.019 ~{RXT}/GPIO.118 RS485/GPIO.2 17 ~{WAKEUP}/GPIO.316 GPIO.4 22 GPIO.5 21 GPIO.6 20 CHREN 13 CHR0 15 CHR1 14 U2 CP2102N-Axx-xQFN28 GND GND
VIN

3 TXD 26 RXD 25 ~{RTS} 24 ~{CTS} 23 ~{DSR} 27 ~{DTR} 28 ~{DCD}1 ~{RI}/CLK2 SUSPEND 12 ~{SUSPEND}11 ~{TXT}/GPIO.019 ~{RXT}/GPIO.118 RS485/GPIO.2 17 ~{WAKEUP}/GPIO.316 GPIO.4 22 GPIO.5 21 GPIO.6 20 CHREN 13 CHR0 15 CHR1 14 GND

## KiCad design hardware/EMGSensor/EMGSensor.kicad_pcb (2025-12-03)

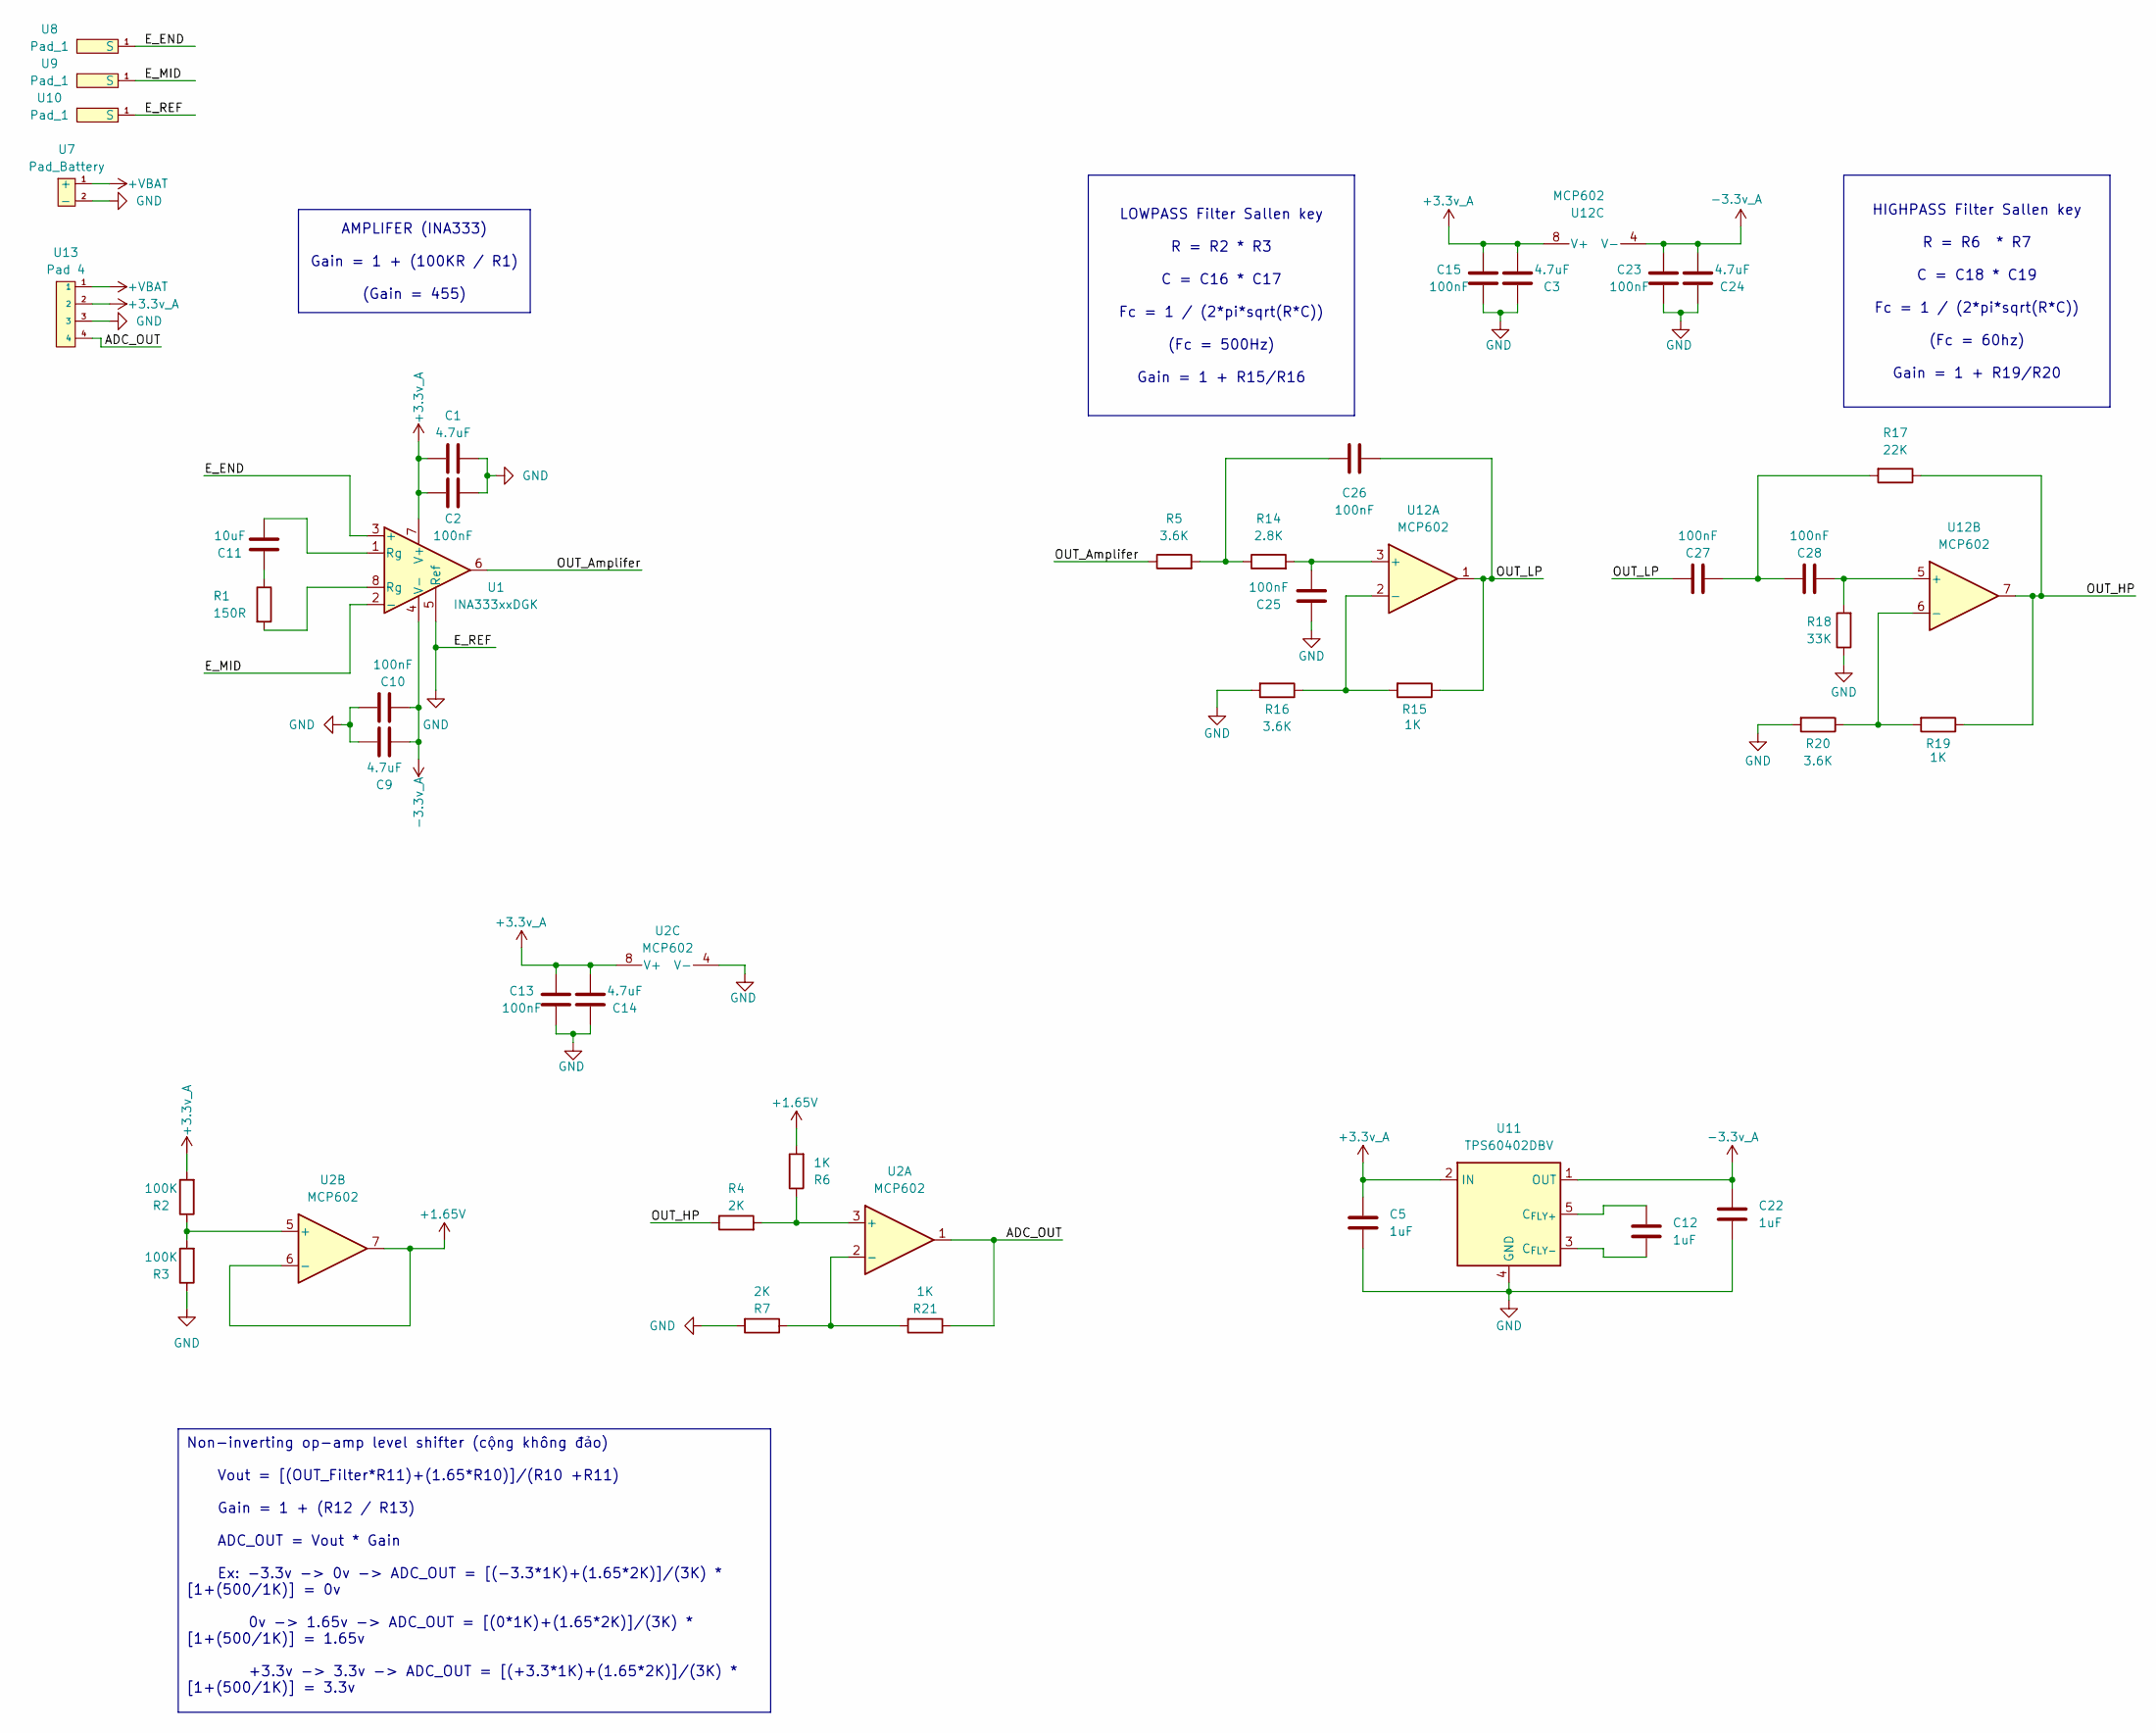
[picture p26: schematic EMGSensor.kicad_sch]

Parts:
C1, C3, C9, C14, C24: 4.7uF; C_0402_1005Metric
C2, C10, C13, C15, C23, C25, C26, C27, C28: 100nF; C_0402_1005Metric
C5, C12, C22: 1uF; C_0402_1005Metric
C11: 10uF; C_0603_1608Metric
R1: 150R; R_0402_1005Metric
R2, R3: 100K; R_0402_1005Metric
R4, R7: 2K; R_0402_1005Metric
R5, R16, R20: 3.6K; R_0402_1005Metric
R6, R15, R19, R21: 1K; R_0402_1005Metric
R14: 2.8K; R_0402_1005Metric
R17: 22K; R_0402_1005Metric
R18: 33K; R_0402_1005Metric
U1: INA333xxDGK; VSSOP-8_3x3mm_P0.65mm
U2, U12: MCP602; SOIC-8_3.9x4.9mm_P1.27mm
U7: Pad_Battery; Pad Battery
U8, U9, U10: Pad_1; Pad 1
U11: TPS60402DBV; SOT-23-5
U13: Pad 4

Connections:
+1.65V: R6.2, U2.6 (-), U2.7
+3.3v_A: C1.1, C2.1, C3.1, C5.1, C13.1, C14.1, C15.1, R2.2, U1.7 (V+), U2.8 (V+), U11.2 (IN), U12.8 (V+), U13.2
+VBAT: U7.1 (+), U13.1
-3.3v_A: C9.1, C10.1, C22.1, C23.1, C24.1, U1.4 (V-), U11.1 (OUT), U12.4 (V-)
/ADC_OUT: R21.1, U2.1, U13.4
/E_END: U1.3 (+), U8.1
/E_MID: U1.2 (-), U9.1
/OUT_Amplifer: R5.1, U1.6
/OUT_HP: R4.1, R17.1, R19.1, U12.7
/OUT_LP: C26.1, C27.2, R15.1, U12.1
GND: C1.2, C2.2, C3.2, C5.2, C9.2, C10.2, C13.2, C14.2, C15.2, C22.2, C23.2, C24.2, C25.1, R3.1, R7.2, R16.2, R18.1, R20.2, U1.5 (Ref), U2.4 (V-), U7.2 (-), U10.1 (S), U11.4 (GND), U13.3
unnamed: C11.1, R1.1
unnamed: C11.2, U1.1 (Rg)
unnamed: C26.2, R5.2, R14.1
unnamed: C27.1, C28.2, R17.2
unnamed: R1.2, U1.8 (Rg)
unnamed: R4.2, R6.1, U2.3 (+)
unnamed: R7.1, R21.2, U2.2 (-)
unnamed: R2.1, R3.2, U2.5 (+)
unnamed: C12.1, U11.5 (C_{FLY+})
unnamed: C12.2, U11.3 (C_{FLY-})
unnamed: C25.2, R14.2, U12.3 (+)
unnamed: R15.2, R16.1, U12.2 (-)
unnamed: C28.1, R18.2, U12.5 (+)
unnamed: R19.2, R20.1, U12.6 (-)

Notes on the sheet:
Non-inverting op-amp level shifter (cộng không đảo) Vout = [(OUT_Filter*R11)+(1.65*R10)]/(R10 +R11) Gain = 1 + (R12 / R13) ADC_OUT = Vout * Gain Ex: -3.3v -> 0v -> ADC_OUT = [(-3.3*1K)+(1.65*2K)]/(3K) * [1+(500/1K)] = 0v 0v -> 1.65v -> ADC_OUT = [(0*1K)+(1.65*2K)]/(3K) * [1+(500/1K)] = 1.65v +3.3v 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
LOWPASS Filter Sallen key R = R2 * R3 C = C16 * C17 Fc = 1 / (2*pi*sqrt(R*C)) (Fc = 500Hz) Gain = 1 + R15/R16
AMPLIFER (INA333) Gain = 1 + (100KR / R1) (Gain = 455)
HIGHPASS Filter Sallen key R = R6 * R7 C = C18 * C19 Fc = 1 / (2*pi*sqrt(R*C)) (Fc = 60hz) Gain = 1 + R19/R20

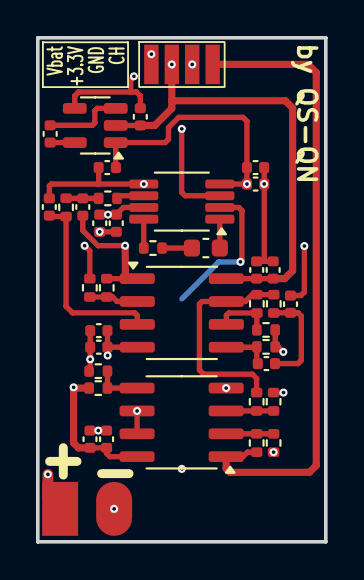
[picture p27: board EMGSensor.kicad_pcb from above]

Board: 4 copper layers, 16.0 x 28.0 mm, 40 parts (0 on the bottom side), 23 nets.

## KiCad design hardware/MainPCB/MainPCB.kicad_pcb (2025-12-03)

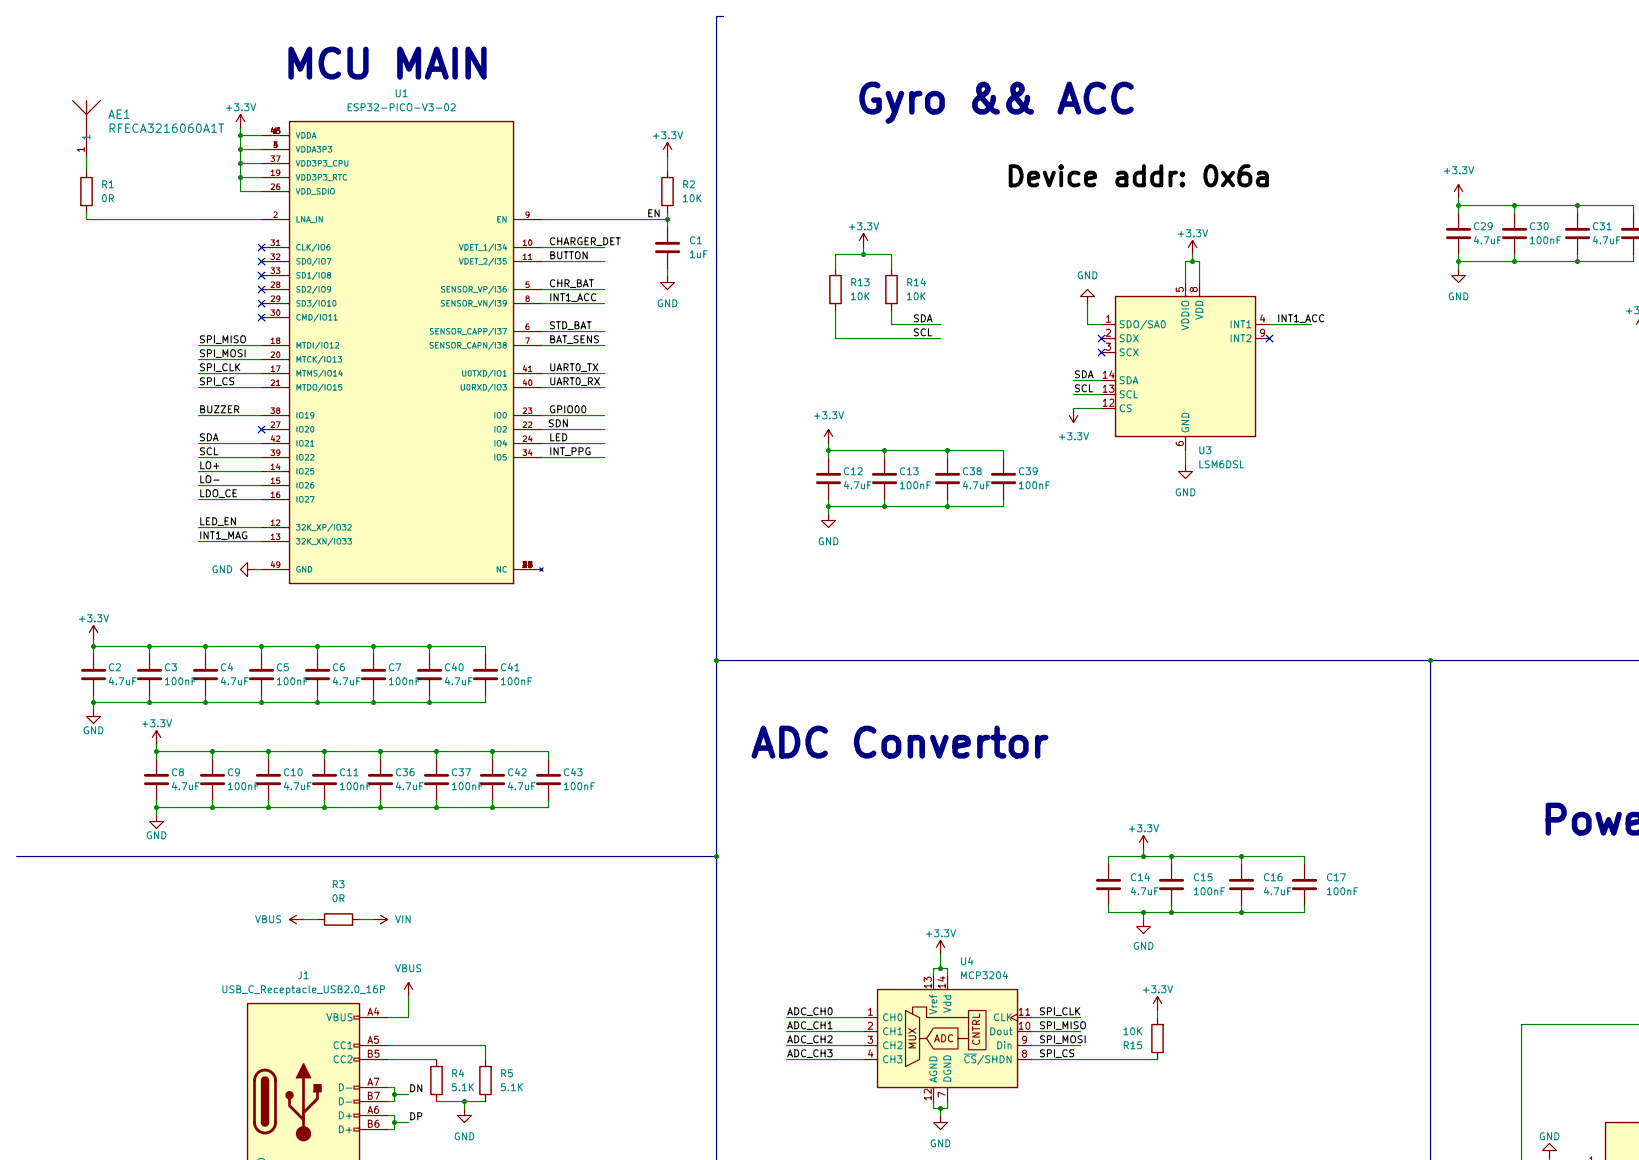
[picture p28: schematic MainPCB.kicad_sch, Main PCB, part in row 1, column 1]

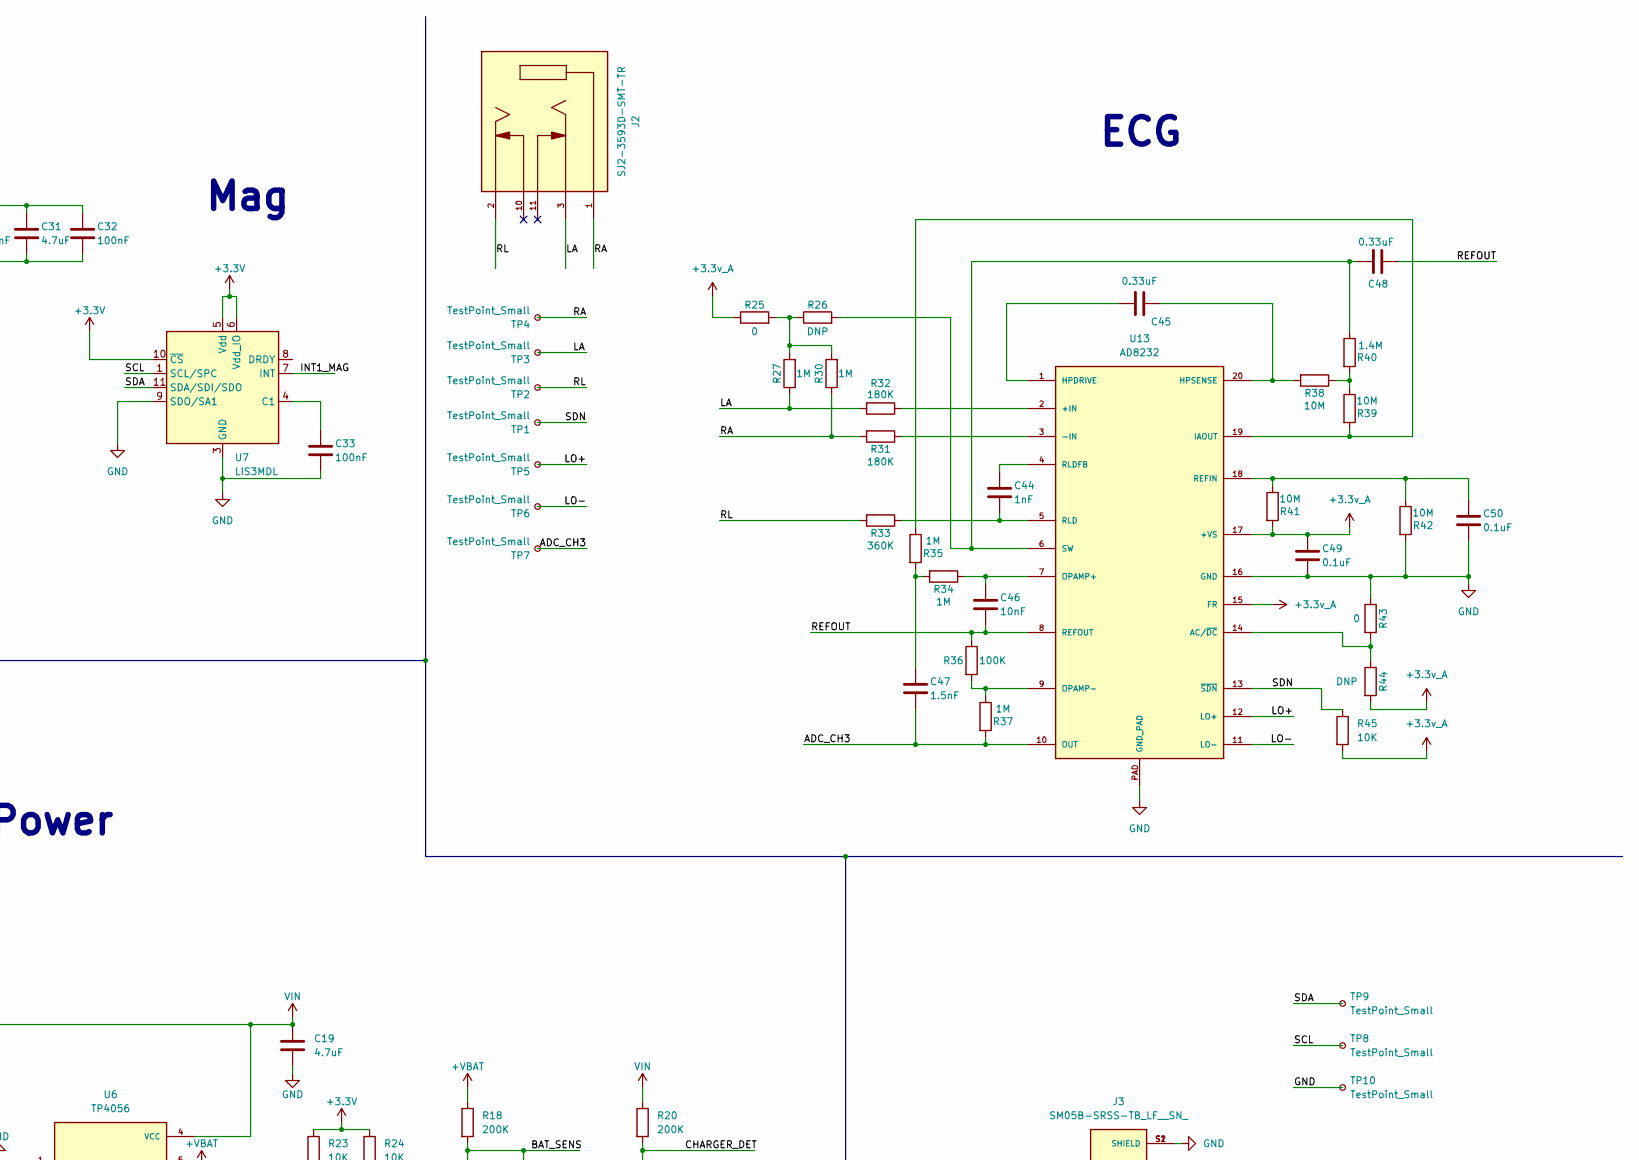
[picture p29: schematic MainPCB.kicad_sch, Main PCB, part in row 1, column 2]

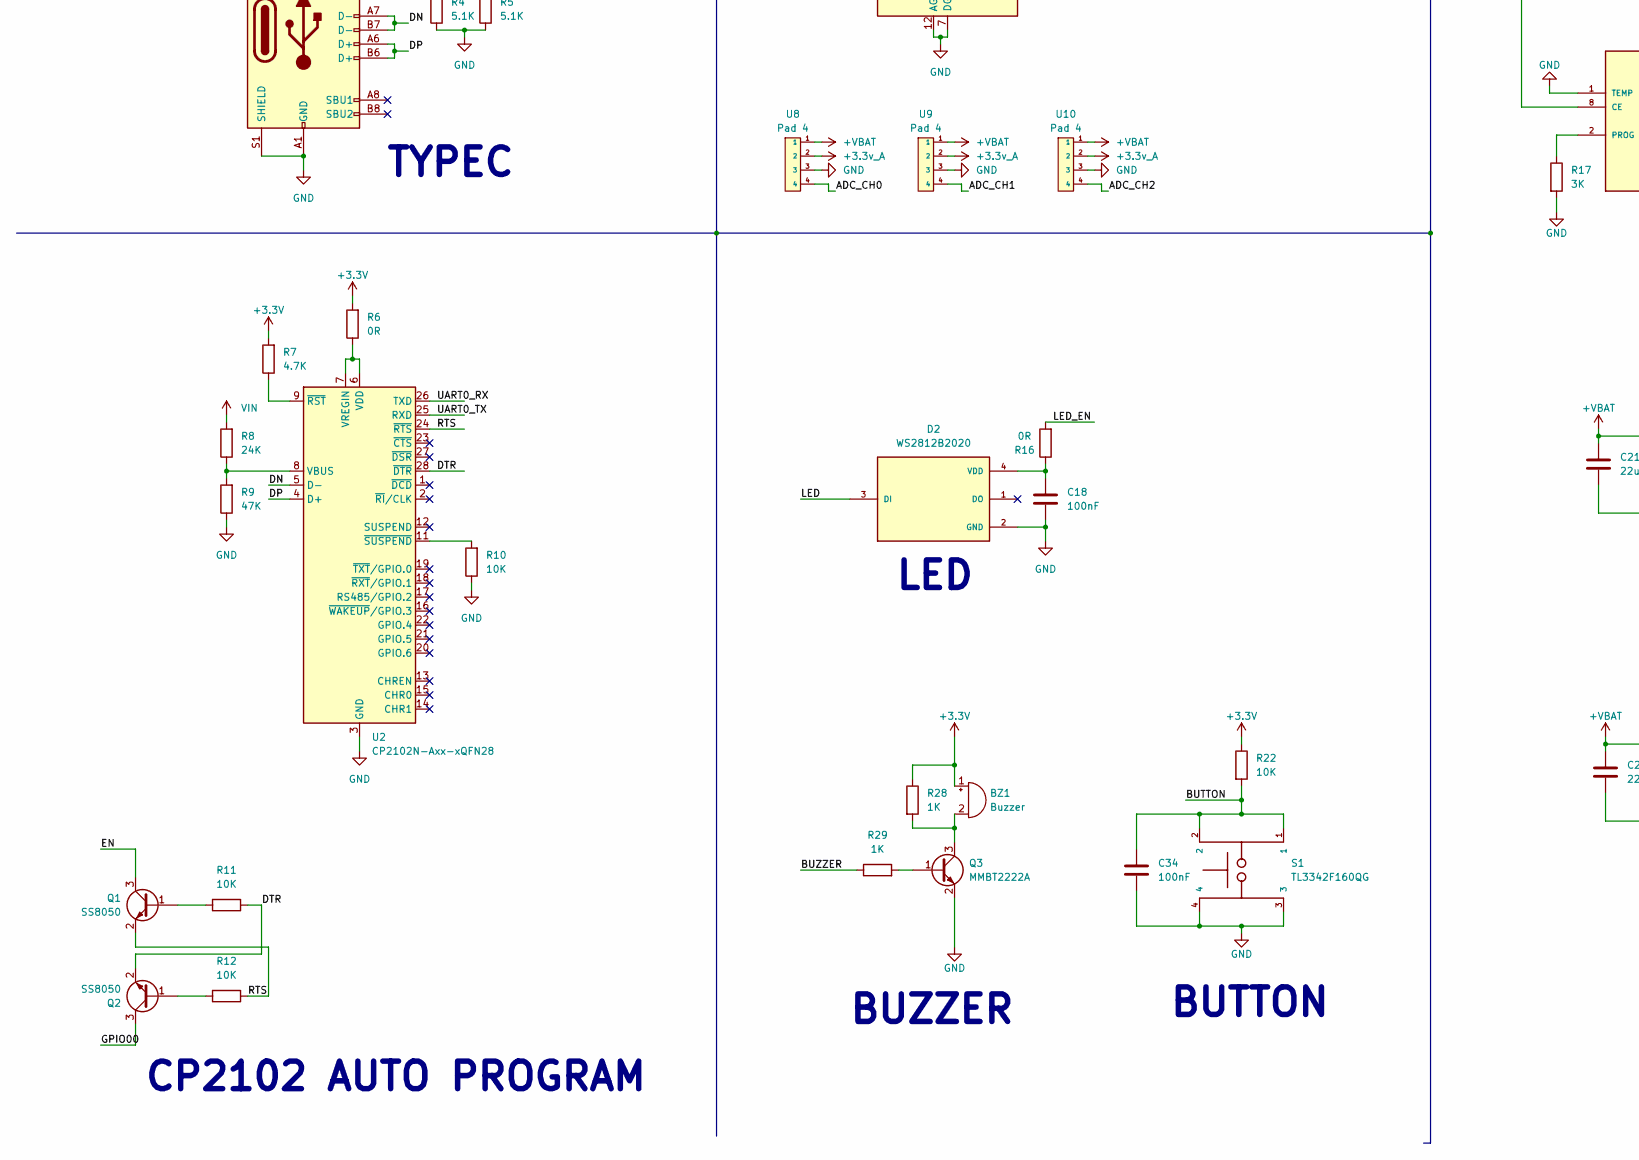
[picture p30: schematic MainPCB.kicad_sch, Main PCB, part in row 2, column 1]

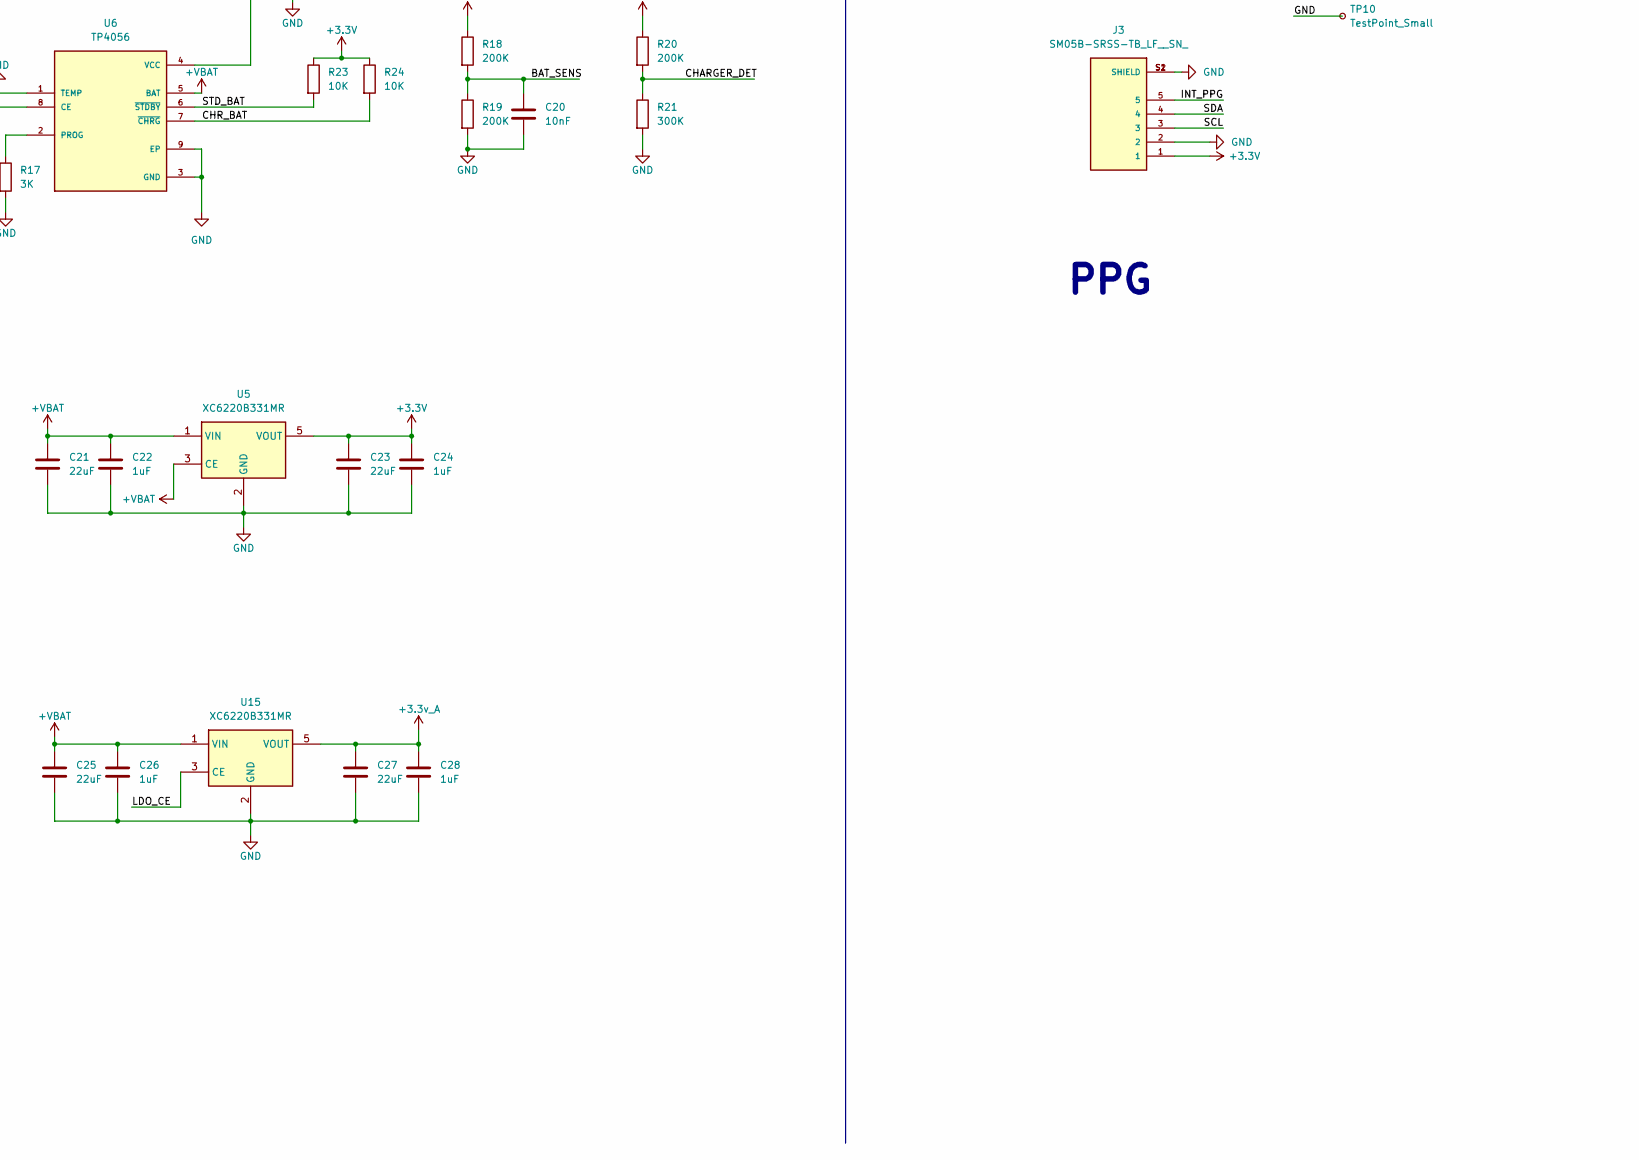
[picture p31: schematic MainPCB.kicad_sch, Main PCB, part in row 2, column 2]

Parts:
AE1: RFECA3216060A1T; ANT_16060A1T_WAL
BZ1: Buzzer; Buzzer_Murata_PKMCS0909E
C1, C22, C24, C26, C28: 1uF; C_0402_1005Metric
C2, C4, C6, C8, C10, C12, C14, C16, C19, C29, C31, C36, C38, C40, C42: 4.7uF; C_0402_1005Metric
C3, C5, C7, C9, C11, C13, C15, C17, C18, C30, C32, C33, C34, C37, C39, C41, C43: 100nF; C_0402_1005Metric
C20, C46: 10nF; C_0402_1005Metric
C21, C23, C25, C27: 22uF; C_0603_1608Metric
C44: 1nF; C_0402_1005Metric
C45, C48: 0.33uF; C_0402_1005Metric
C47: 1.5nF; C_0402_1005Metric
C49, C50: 0.1uF; C_0402_1005Metric
D2: WS2812B2020; LED_WS2812B2020; PARTREV V1.0
J1: USB_C_Receptacle_USB2.0_16P; USB_C_Receptacle_GCT_USB4105-xx-A_16P_TopMnt_Horizontal
J2: SJ2-3593D-SMT-TR; CUI_SJ2-3593D-SMT-TR; PARTREV 1.04
J3: SM05B-SRSS-TB_LF__SN_; JST_SM05B-SRSS-TB_LF__SN_
Q1, Q2: SS8050; SOT-23
Q3: MMBT2222A; SOT-23
R1, R3, R6, R16: 0R; C_0402_1005Metric
R2, R10, R11, R12, R13, R14, R15, R22, R23, R24, R45: 10K; C_0402_1005Metric
R4, R5: 5.1K; C_0402_1005Metric
R7: 4.7K; C_0402_1005Metric
R8: 24K; C_0402_1005Metric
R9: 47K; C_0402_1005Metric
R17: 3K; C_0402_1005Metric
R18, R19, R20: 200K; C_0402_1005Metric
R21: 300K; C_0402_1005Metric
R25, R43: 0; C_0402_1005Metric
R26, R44: DNP; C_0402_1005Metric
R27, R30, R34, R35, R37: 1M; C_0402_1005Metric
R28, R29: 1K; C_0402_1005Metric
R31, R32: 180K; C_0402_1005Metric
R33: 360K; C_0402_1005Metric
R36: 100K; C_0402_1005Metric
R38, R39, R41, R42: 10M; C_0402_1005Metric
R40: 1.4M; C_0402_1005Metric
S1: TL3342F160QG; SW_TL3342F160QG
TP1, TP2, TP3, TP4, TP5, TP6, TP7, TP8, TP9, TP10: TestPoint_Small; TestPoint_Pad_D1.0mm
U1: ESP32-PICO-V3-02; XCVR_ESP32-PICO-V3-02; PARTREV 1.0
U2: CP2102N-Axx-xQFN28; QFN-28-1EP_5x5mm_P0.5mm_EP3.35x3.35mm
U3: LSM6DSL; LGA-14_3x2.5mm_P0.5mm_LayoutBorder3x4y
U4: MCP3204; TSSOP-14_4.4x5mm_P0.65mm
U5, U15: XC6220B331MR; SOT-23-5
U6: TP4056; SOP127P600X175-9N
U7: LIS3MDL; LGA-12_2x2mm_P0.5mm
U8, U9, U10: Pad 4
U13: AD8232; LFCSP_20

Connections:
+3.3V: BZ1.1 (+), C2.1, C3.1, C4.1, C5.1, C6.1, C7.1, C8.1, C9.1, C10.1, C11.1, C12.1, C13.1, C14.1, C15.1, C16.1, C17.1, C23.1, C24.1, C29.1, C30.1, C31.1, C32.1, C36.1, C37.1, C38.1, C39.1, C40.1, C41.1, C42.1, C43.1, J3.1, R2.1, R6.2, R7.2, R13.1, R14.1, R15.2, R22.1, R23.1, R24.1, R28.1, U1.1 (VDDA), U1.3 (VDDA3P3), U1.4 (VDDA3P3), U1.19 (VDD3P3_RTC), U1.26 (VDD_SDIO), U1.37 (VDD3P3_CPU), U1.43 (VDDA), U1.46 (VDDA), U3.5 (VDDIO), U3.8 (VDD), U3.12 (CS), U4.13 (Vref), U4.14 (Vdd), U5.5 (VOUT), U7.5 (Vdd), U7.6 (Vdd_IO), U7.10 (~CS)
+3.3v_A: C27.1, C28.1, C49.1, R25.1, R41.2, R44.2, R45.2, U8.2, U9.2, U10.2, U13.15 (FR), U13.17 (+VS), U15.5 (VOUT)
+VBAT: C21.1, C22.1, C25.1, C26.1, R18.1, U5.1 (VIN), U5.3 (CE), U6.5 (BAT), U8.1, U9.1, U10.1, U15.1 (VIN)
/ADC_CH0: U4.1 (CH0), U8.4
/ADC_CH1: U4.2 (CH1), U9.4
/ADC_CH2: U4.3 (CH2), U10.4
/ADC_CH3: C47.2, R37.2, TP7.1, U4.4 (CH3), U13.10 (OUT)
/BAT_SENS: C20.1, R18.2, R19.1, U1.7 (SENSOR_CAPN/I38)
/BUTTON: C34.1, R22.2, S1.1, S1.2, U1.11 (VDET_2/I35)
/BUZZER: R29.1, U1.38 (IO19)
/CHARGER_DET: R20.2, R21.1, U1.10 (VDET_1/I34)
/CHR_BAT: R24.2, U1.5 (SENSOR_VP/I36), U6.7 (~CHRG)
/DN: J1.A7 (D-), J1.B7 (D-), U2.5 (D-)
/DP: J1.A6 (D+), J1.B6 (D+), U2.4 (D+)
/DTR: Q2.2 (E), R11.1, U2.28 (~DTR)
/EN: C1.1, Q1.3 (C), R2.2, U1.9 (EN)
/GPIO00: Q2.3 (C), U1.23 (IO0)
/INT1_ACC: U1.8 (SENSOR_VN/I39), U3.4 (INT1)
/INT1_MAG: U1.13 (32K_XN/IO33), U7.7 (INT)
/INT_PPG: J3.5, U1.34 (IO5)
/LA: J2.3, R27.1, R32.2, TP3.1
/LDO_CE: U1.16 (IO27), U15.3 (CE)
/LED: D2.3 (DI), U1.24 (IO4)
/LED_EN: R16.2, U1.12 (32K_XP/IO32)
/LO+: TP5.1, U1.14 (IO25), U13.12 (LO+)
/LO-: TP6.1, U1.15 (IO26), U13.11 (LO-)
/RA: J2.1, R30.1, R31.2, TP4.1
/REFOUT: C46.2, C48.2, R36.1, U13.8 (REFOUT)
/RL: J2.2, R33.2, TP2.1
/RTS: Q1.2 (E), R12.1, U2.24 (~RTS)
/SCL: J3.3, R13.2, TP8.1, U1.39 (IO22), U3.13 (SCL), U7.1 (SCL/SPC)
/SDA: J3.4, R14.2, TP9.1, U1.42 (IO21), U3.14 (SDA), U7.11 (SDA/SDI/SDO)
/SDN: R45.1, TP1.1, U1.22 (IO2), U13.13 (~SDN)
/SPI_CLK: U1.17 (MTMS/IO14), U4.11 (CLK)
/SPI_CS: R15.1, U1.21 (MTDO/IO15), U4.8 (~CS/SHDN)
/SPI_MISO: U1.18 (MTDI/IO12), U4.10 (Dout)
/SPI_MOSI: U1.20 (MTCK/IO13), U4.9 (Din)
/STD_BAT: R23.2, U1.6 (SENSOR_CAPP/I37), U6.6 (~STDBY)
/UART0_RX: U1.40 (U0RXD/IO3), U2.26 (TXD)
/UART0_TX: U1.41 (U0TXD/IO1), U2.25 (RXD)
GND: C1.2, C2.2, C3.2, C4.2, C5.2, C6.2, C7.2, C8.2, C9.2, C10.2, C11.2, C12.2, C13.2, C14.2, C15.2, C16.2, C17.2, C18.2, C19.2, C20.2, C21.2, C22.2, C23.2, C24.2, C25.2, C26.2, C27.2, C28.2, C29.2, C30.2, C31.2, C32.2, C33.2, C34.2, C36.2, C37.2, C38.2, C39.2, C40.2, C41.2, C42.2, C43.2, C49.2, C50.2, D2.2 (GND), J1.A1 (GND), J1.A12 (GND), J1.B1 (GND), J1.B12 (GND), J1.S1 (SHIELD), J3.2, J3.S1 (SHIELD), J3.S2 (SHIELD), Q3.2 (E), R4.1, R5.1, R9.1, R10.1, R17.2, R19.2, R21.2, R42.2, R43.1, S1.3, S1.4, TP10.1, U1.49 (GND), U2.3 (GND), U2.29 (GND), U3.1 (SDO/SA0), U3.6 (GND), U3.7 (GND), U4.7 (DGND), U4.12 (AGND), U5.2 (GND), U6.1 (TEMP), U6.3 (GND), U6.9 (EP), U7.2 (GND), U7.3 (GND), U7.9 (SDO/SA1), U7.12 (GND), U8.3, U9.3, U10.3, U13.16 (GND), U13.PAD (GND_PAD), U15.2 (GND)
unnamed: AE1.1, R1.1
unnamed: BZ1.2 (-), Q3.3 (C), R28.2
unnamed: C47.1, R34.2, R35.2
unnamed: C18.1, D2.4 (VDD), R16.1
unnamed: J1.A5 (CC1), R5.2
unnamed: J1.B5 (CC2), R4.2
unnamed: Q1.1 (B), R11.2
unnamed: Q2.1 (B), R12.2
unnamed: Q3.1 (B), R29.2
unnamed: R25.2, R26.1, R27.2, R30.2
unnamed: R38.1, R39.1, R40.2
unnamed: R1.2, U1.2 (LNA_IN)
unnamed: R8.1, R9.2, U2.8 (VBUS)
unnamed: R6.1, U2.6 (VDD), U2.7 (VREGIN)
unnamed: R7.1, U2.9 (~RST)
unnamed: R10.2, U2.11 (~SUSPEND)
unnamed: R17.1, U6.2 (PROG)
unnamed: C33.1, U7.4 (C1)
unnamed: R32.1, U13.2 (+IN)
unnamed: R31.1, U13.3 (-IN)
unnamed: R43.2, R44.1, U13.14 (AC/~DC)
unnamed: C45.1, U13.1 (HPDRIVE)
unnamed: C45.2, R38.2, U13.20 (HPSENSE)
unnamed: R35.1, R39.2, U13.19 (IAOUT)
unnamed: C46.1, R34.1, U13.7 (OPAMP+)
unnamed: R36.2, R37.1, U13.9 (OPAMP-)
unnamed: C50.1, R41.1, R42.1, U13.18 (REFIN)
unnamed: C44.2, R33.1, U13.5 (RLD)
unnamed: C44.1, U13.4 (RLDFB)
unnamed: C48.1, R26.2, R40.1, U13.6 (SW)
VBUS: J1.A4 (VBUS), J1.A9 (VBUS), J1.B4 (VBUS), J1.B9 (VBUS), R3.1
VIN: C19.1, R3.2, R8.2, R20.1, U6.4 (VCC), U6.8 (CE)

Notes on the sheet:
PPG
LED
BUZZER
ADC Convertor
Power
Gyro && ACC
CP2102 AUTO PROGRAM
Mag
TYPEC
ECG
BUTTON
MCU MAIN

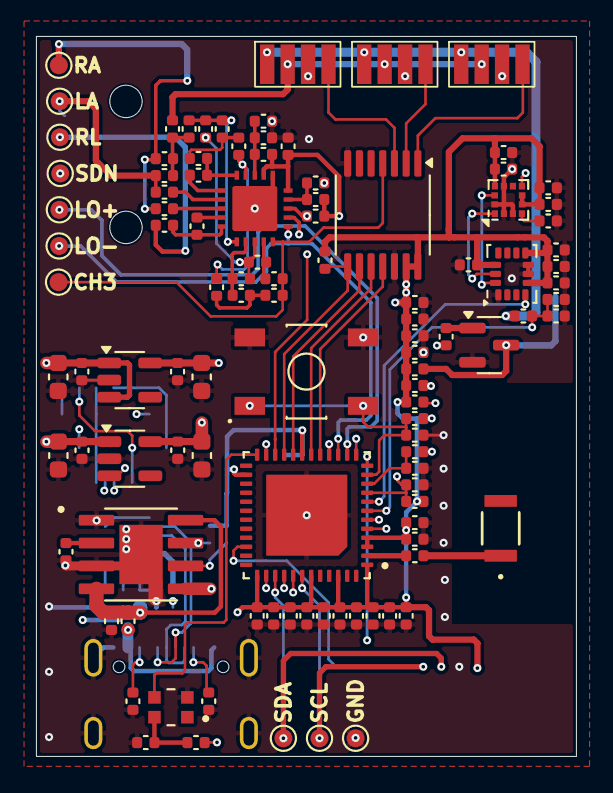
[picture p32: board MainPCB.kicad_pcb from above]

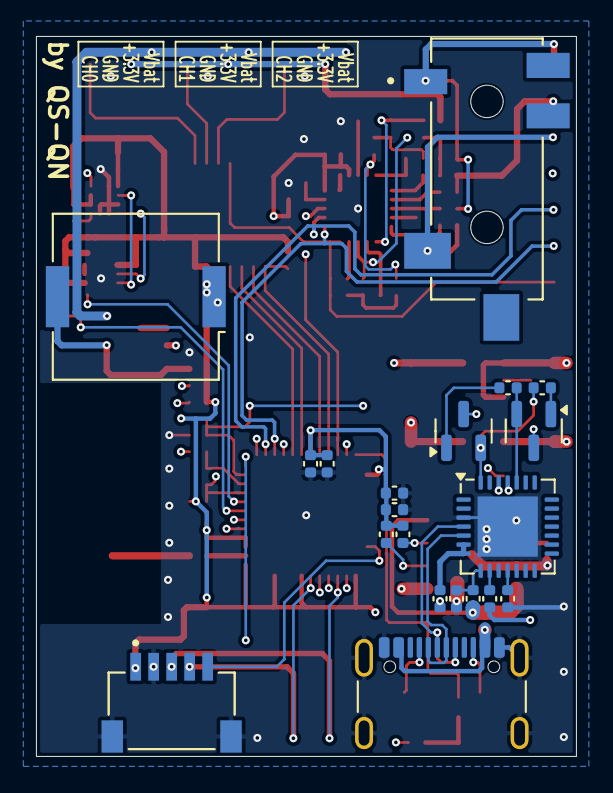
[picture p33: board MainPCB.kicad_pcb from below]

Board: 4 copper layers, 30.0 x 40.0 mm, 126 parts (20 on the bottom side), 73 nets.

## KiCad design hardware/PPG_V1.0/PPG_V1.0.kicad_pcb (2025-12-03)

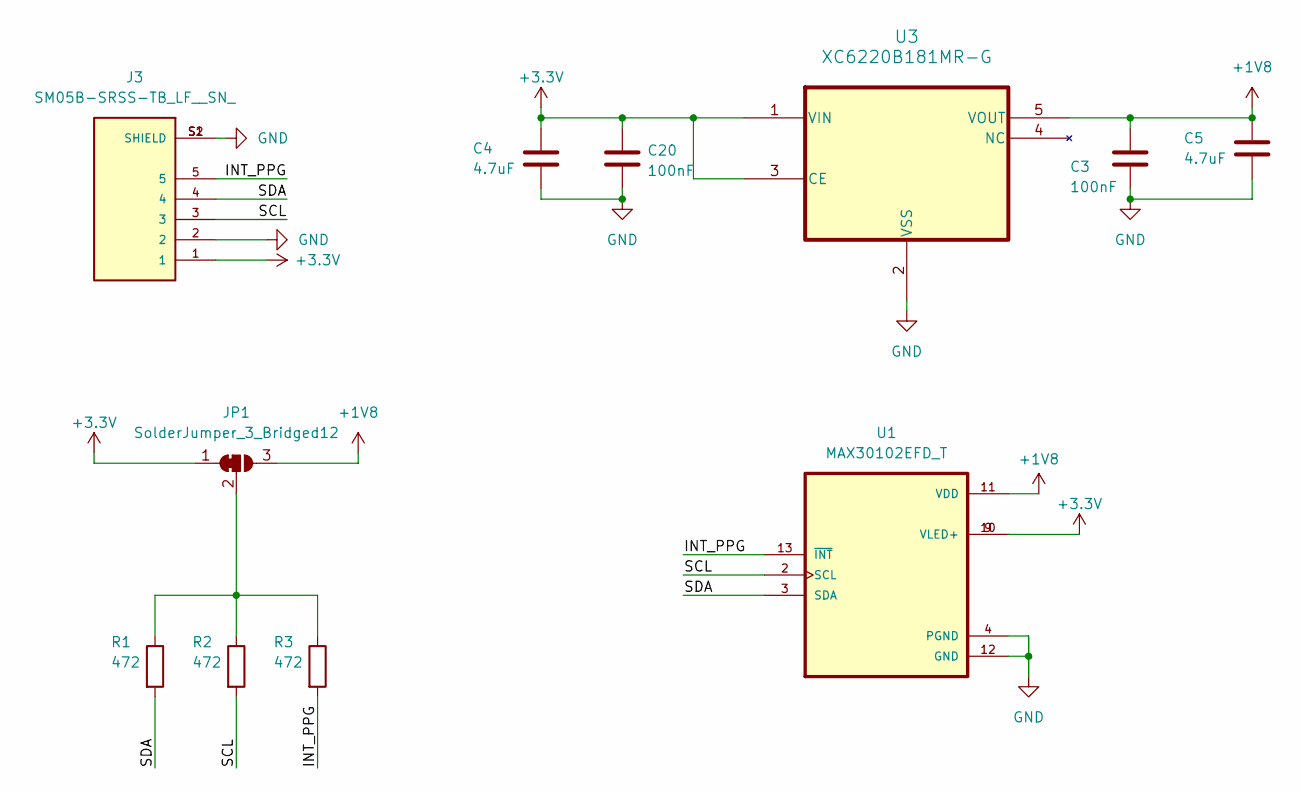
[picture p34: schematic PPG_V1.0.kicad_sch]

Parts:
C3, C20: 100nF; C_0402_1005Metric
C4, C5: 4.7uF; C_0402_1005Metric
J3: SM05B-SRSS-TB_LF__SN_; JST_SM05B-SRSS-TB_LF__SN_
JP1: SolderJumper_3_Bridged12; SolderJumper-3_P1.3mm_Bridged12_RoundedPad1.0x1.5mm_NumberL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
R1, R2, R3: 472; C_0402_1005Metric
U1: MAX30102EFD_T; XDCR_MAX30101EFD_
U3: XC6220B181MR-G; SOT-25_TOR

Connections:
+1V8: C3.1, C5.1, JP1.3 (B), U1.11 (VDD), U3.5 (VOUT)
+3.3V: C4.1, C20.1, J3.1, JP1.1 (A), U1.9 (VLED+), U1.10 (VLED+), U3.1 (VIN), U3.3 (CE)
/INT_PPG: J3.5, R3.2, U1.13 (~INT)
/SCL: J3.3, R2.2, U1.2 (SCL)
/SDA: J3.4, R1.2, U1.3 (SDA)
GND: C3.2, C4.2, C5.2, C20.2, J3.2, J3.S1 (SHIELD), J3.S2 (SHIELD), U1.4 (PGND), U1.12 (GND), U3.2 (VSS)
unnamed: JP1.2 (C), R1.1, R2.1, R3.1

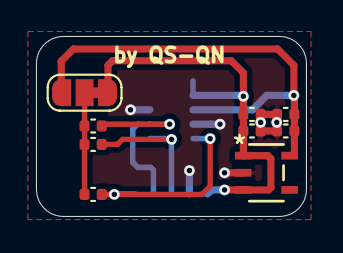
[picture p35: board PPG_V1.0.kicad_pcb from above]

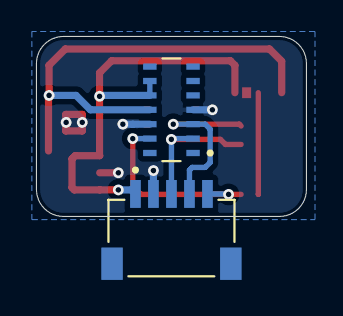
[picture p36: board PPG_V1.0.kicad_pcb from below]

Board: 2 copper layers, 15.0 x 10.0 mm, 11 parts (2 on the bottom side), 7 nets.

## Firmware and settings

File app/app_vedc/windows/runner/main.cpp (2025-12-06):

#include <flutter/dart_project.h>
#include <flutter/flutter_view_controller.h>
#include <windows.h>

#include "flutter_window.h"
#include "utils.h"

int APIENTRY wWinMain(_In_ HINSTANCE instance, _In_opt_ HINSTANCE prev,
                      _In_ wchar_t *command_line, _In_ int show_command) {
  // Attach to console when present (e.g., 'flutter run') or create a
  // new console when running with a debugger.
  if (!::AttachConsole(ATTACH_PARENT_PROCESS) && ::IsDebuggerPresent()) {
    CreateAndAttachConsole();
  }

  // Initialize COM, so that it is available for use in the library and/or
  // plugins.
  ::CoInitializeEx(nullptr, COINIT_APARTMENTTHREADED);

  flutter::DartProject project(L"data");

  std::vector<std::string> command_line_arguments =
      GetCommandLineArguments();

  project.set_dart_entrypoint_arguments(std::move(command_line_arguments));

  FlutterWindow window(project);
  Win32Window::Point origin(10, 10);
  Win32Window::Size size(1280, 720);
  if (!window.Create(L"app_vedc", origin, size)) {
    return EXIT_FAILURE;
  }
  window.SetQuitOnClose(true);

  ::MSG msg;
  while (::GetMessage(&msg, nullptr, 0, 0)) {
    ::TranslateMessage(&msg);
    ::DispatchMessage(&msg);
  }

  ::CoUninitialize();
  return EXIT_SUCCESS;
}

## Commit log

2025-12-03 feature: additional drawing hardware
    [EMGSensor.kicad_pcb, EMGSensor.kicad_sch, EMGSensor.step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]
2025-12-09 feature: add firebase, add send data email, add 3d imu simulation, optime FW
    [imu.obj]

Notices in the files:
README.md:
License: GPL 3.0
